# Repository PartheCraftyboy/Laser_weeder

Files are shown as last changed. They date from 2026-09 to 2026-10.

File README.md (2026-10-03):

# Jim — Precision 2-DOF Laser Weeding Gantry

<div align="center">








**Sub-millimeter autonomous laser weeding gantry system built on ROS 2 Jazzy, Gazebo Harmonic, and `ros2_control`.**

</div>

---

<div align="center">
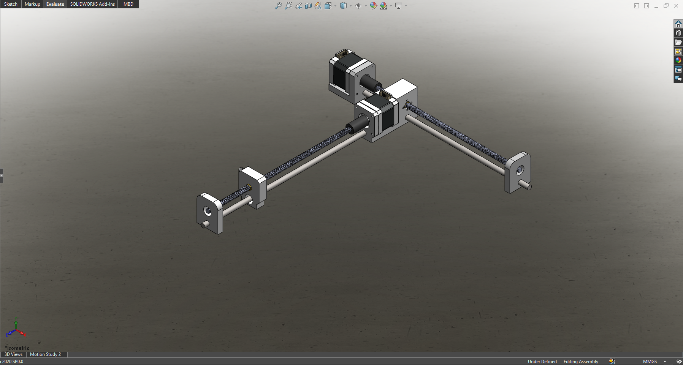
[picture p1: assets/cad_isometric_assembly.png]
Jim 2-DOF Gantry CAD Isometric Assembly
  
  <p><em>Figure 1: Full 3D CAD mechanical assembly of the Jim 2-DOF Cartesian laser weeding gantry.</em></p>
</div>

---

## 📖 Table of Contents

- [Executive Summary](#-executive-summary)
- [Mechanical & CAD Architecture](#-mechanical--cad-architecture)
  - [3D CAD Models & Assemblies](#3d-cad-models--assemblies)
  - [Finite Element Analysis (FEA)](#finite-element-analysis-fea)
  - [Kinematics & Hard Engineering Specs](#kinematics--hard-engineering-specs)
- [Software & Control Architecture](#-software--control-architecture)
  - [High-Level Dataflow](#high-level-dataflow)
  - [Coordinate Frames & TF Tree](#coordinate-frames--tf-tree)
  - [Defensible Engineering Decisions](#defensible-engineering-decisions)
- [ROS 2 Packages Breakdown](#-ros-2-packages-breakdown)
- [Quickstart Guide](#-quickstart-guide)
  - [Prerequisites](#prerequisites)
  - [One-Command Launch (Docker)](#one-command-launch-docker)
  - [Manual Docker Workflow](#manual-docker-workflow)
- [Targeting & Perception Pipeline](#-targeting--perception-pipeline)
  - [Field Generation](#field-generation)
  - [Oracle Weed Detector](#oracle-weed-detector)
  - [Analytical TF Targeting](#analytical-tf-targeting)
- [Hardware Implementation Roadmap](#-hardware-implementation-roadmap)
- [License & Acknowledgments](#-license--acknowledgments)

---

## 🌿 Executive Summary

**Jim** is an autonomous agricultural robot designed for targeted non-chemical weed eradication. Unlike bulky field robots or complex multi-axis articulated arms, Jim utilizes a static **2-DOF Cartesian gantry** suspended 300 mm above a 250 mm × 250 mm agricultural plot.

A downward-facing perception stack identifies weeds in real time, and the dual-axis gantry positions a focused optical laser beam with sub-millimeter precision over each weed meristem to eliminate it without disturbing adjacent crop root systems or compacting soil.

### Core Highlights
* **Zero Overhead IK**: Pure linear TF-based closed-form targeting in 4 lines of Python — no heavy OMPL or sampling configuration space required.
* **Deterministic Motion Control**: Driven via standard `ros2_control` and `JointTrajectoryController`.
* **Photorealistic Harmonic Simulation**: Complete field simulation in Gazebo Harmonic with dynamic procedural crop and weed distribution.
* **Oracle Perception with Synthetic Noise**: Fully decoupled perception testing with configurable runtime noise, miss rates, and false positives.
* **Containerized Environment**: Complete ROS 2 Jazzy + Gazebo Harmonic + GUI pass-through in Docker.

---

## ⚙️ Mechanical & CAD Architecture

The physical gantry is designed from the ground up for rigid, repeatable linear motion, thermal reliability, and rapid additive manufacturing.

<div align="center">
  <table>
    <tr>
      <td align="center" width="50%">
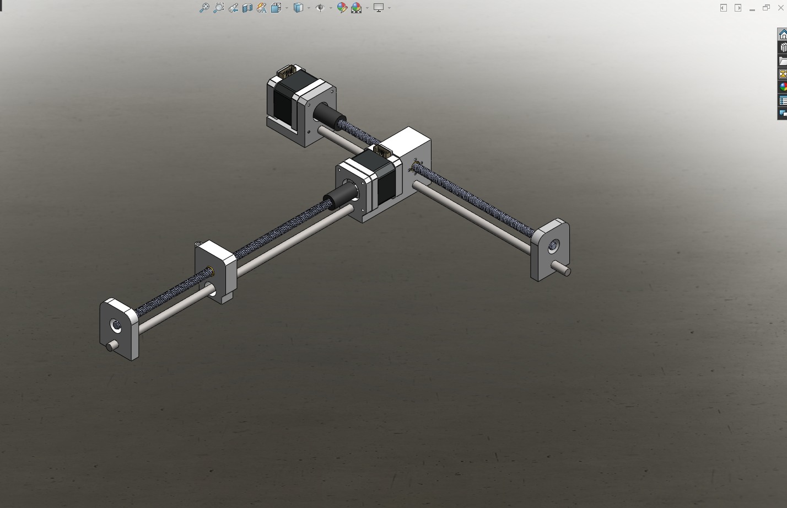
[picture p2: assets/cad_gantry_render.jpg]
CAD Gantry Render
        
        <br />
        <b>Dual-Axis Cross Gantry Assembly</b>
      </td>
      <td align="center" width="50%">
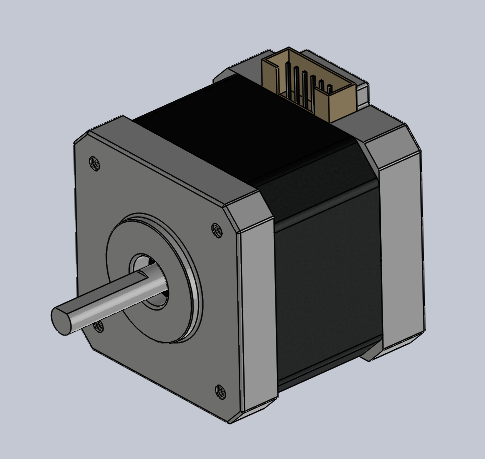
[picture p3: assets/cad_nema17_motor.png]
NEMA 17 Stepper Model
        
        <br />
        <b>NEMA 17 Stepper Actuator Model</b>
      </td>
    </tr>
  </table>
</div>

### 3D CAD Models & Assemblies

All CAD source files are housed under [`Main_Model/`](Main_Model/):
* **Master Assemblies**: `Main.SLDASM`, `jim_description.SLDASM` (configured for URDF/STL export).
* **2D Technical Drawings**: `D1_Main.SLDDRW` with detailed machining tolerances and hole patterns.
* **Drive Components**: T8 lead screws (`lead_screw.SLDPRT`), brass anti-backlash trapezoidal nuts (`nut.SLDPRT`), 8 mm hardened linear guide rods (`Rod.SLDPRT`), and flexible jaw couplers (`Coupler.SLDPRT`).
* **Custom Structural Brackets**: 3D printable brackets (`mount_bracket.STL`, `holding_bracket.STL`, `holding_bracket_y.STL`, `Part6.STL`, `Lazer block^X-axis.STL`).
* **Interchange Formats**: Standard `STEP` format (`Nima 17 40x42x5mm.STEP`) and motion study animation (`assets/cad_motion_study_xaxis.mp4`).

### Finite Element Analysis (FEA)

Structural rigidity is critical: any deflection in the motor bracket under rapid acceleration would translate into beam aiming error at the soil plane.

<div align="center">
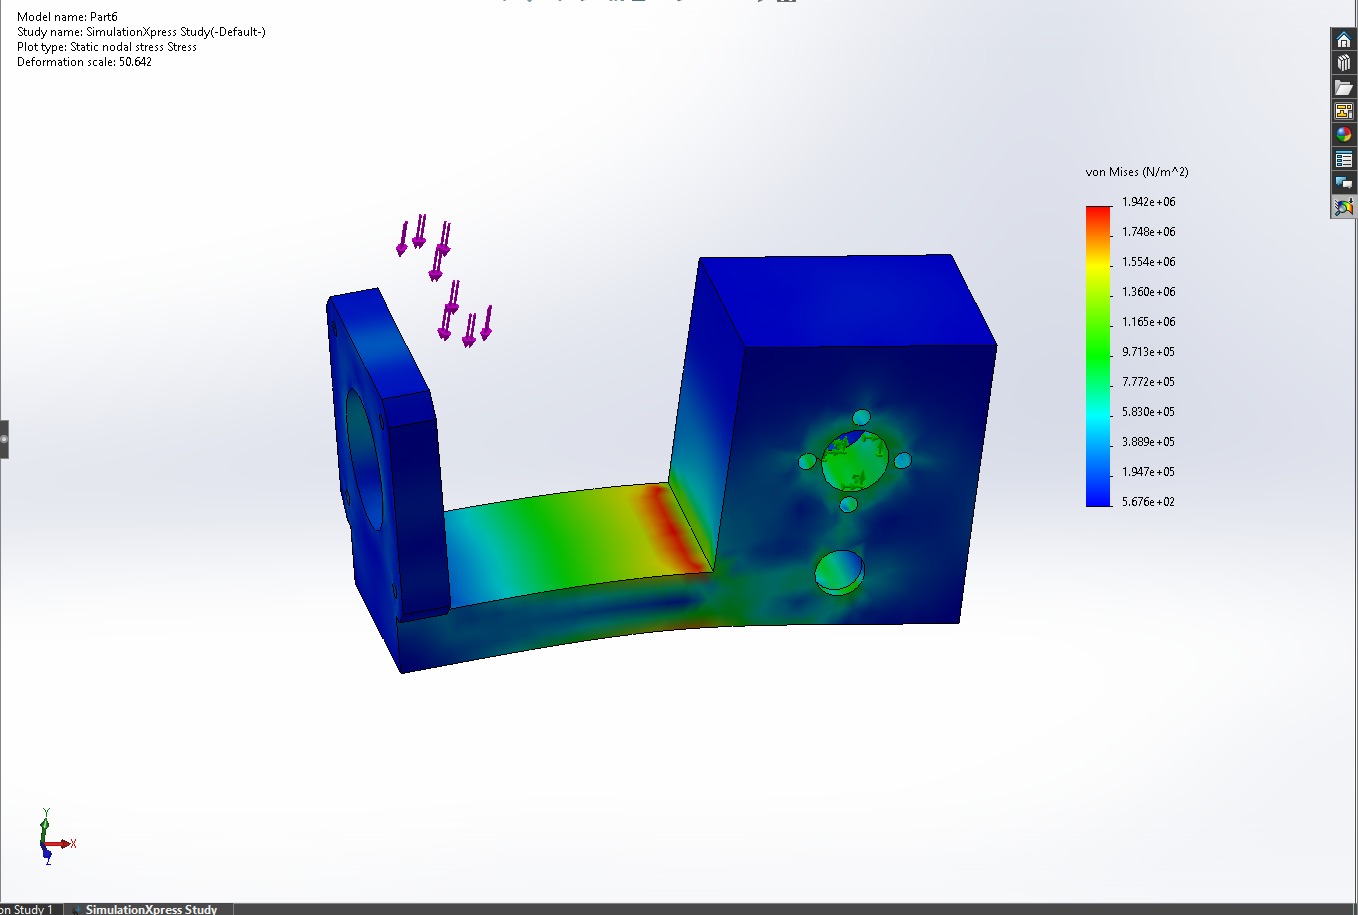
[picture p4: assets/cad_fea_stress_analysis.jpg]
SolidWorks SimulationXpress FEA
  
  <p><em>Figure 2: Finite Element Analysis (FEA) of motor mounting bracket (Part6) in SolidWorks SimulationXpress.</em></p>
</div>

* **Study**: Static nodal stress simulation (von Mises criterion).
* **Max von Mises Stress**: \(1.942 \times 10^6\text{ N/m}^2\) (\(\approx 1.94\text{ MPa}\)).
* **Structural Safety Margin**: Compared against the yield strength of structural PETG/PLA (\(> 45\text{ MPa}\)), the safety factor exceeds **20×**, ensuring zero structural deflection during gantry maneuvers.

### Kinematics & Hard Engineering Specs

| Parameter | Specification | Rationale & Engineering Formula |
| :--- | :--- | :--- |
| **Working Envelope** | \(250\text{ mm} \times 250\text{ mm}\) | Covers standard vegetable/nursery plot grid |
| **Z Height (Beam Clearance)** | \(300\text{ mm}\) above soil | Keeps optics clear of crop canopy and debris |
| **Lead Screws** | T8 (2 mm pitch, 4 starts) | **8 mm lead / revolution** for optimal speed-to-torque balance |
| **Guide Rails** | 8 mm precision hardened steel | Smooth rod with linear sleeve bearings |
| **Full Step Resolution** | **0.04 mm / full step** | \(8\text{ mm / rev} \div 200\text{ steps / rev} = 0.04\text{ mm}\) |
| **16× Microstepping Resolution** | **0.0025 mm / microstep** | \(8\text{ mm / rev} \div 3200\text{ steps / rev} = 2.5\ \mu\text{m}\) |
| **Maximum Safe Velocity** | **0.035 m/s** (\(35\text{ mm/s}\)) | **Lead screw critical whirling speed limit**: \(4.76 \times 10^6 \times 6.2 / 300^2 \approx 328\text{ RPM}\) (80% derated) |
| **Actuators** | NEMA 17 Stepper (1.8° step angle) | Standard form factor with high holding torque |
| **Operating Current** | **0.8 A – 1.0 A** *(NOT 1.5 A)* | 1.5 A drives casing to \(\sim 88^\circ\text{C}\); PLA glass transition \(T_g = 60^\circ\text{C}\) |
| **Torque Margin** | \(\approx 13\text{ mN}\cdot\text{m}\) vs \(400\text{ mN}\cdot\text{m}\) | **\(> 12\times\) holding margin**, preventing skipped steps |
| **Stepper Drivers** | MKS TMC2209 | SilentStepStick with StallGuard sensorless homing |

---

## 🧠 Software & Control Architecture

### High-Level Dataflow

```mermaid
flowchart TD
    subgraph Simulation ["Gazebo Harmonic & Physics"]
        GZ_WORLD["Ground Truth Field (Crops + Weeds)"]
        GZ_ROBOT["Jim URDF + gz_ros2_control Plugin"]
        GZ_CLOCK["Gazebo Clock"]
    end

    subgraph Bridges ["ROS-Gazebo Bridge"]
        BRIDGE_CLOCK["/clock Bridge"]
        BRIDGE_IMAGE["Camera / Image Bridge"]
    end

    subgraph Perception ["Perception & Detection"]
        ORACLE["oracle_detector<br/>(Reads ground_truth.yaml + injects noise)"]
    end

    subgraph Control ["Targeting & Control Stack"]
        TF["TF2 Listener<br/>(/tf & /tf_static)"]
        TARGETING["targeting_node<br/>(Analytical IK: closed-form linear delta)"]
        JTC["JointTrajectoryController<br/>(/gantry_controller)"]
        JSB["joint_state_broadcaster<br/>(/joint_states)"]
    end

    subgraph Visualization ["Operator Interface"]
        RVIZ["RViz2 Visualization<br/>(Aim ray, targets, weed markers)"]
    end

    GZ_CLOCK --> BRIDGE_CLOCK
    GZ_WORLD -.->|Known coordinates| ORACLE
    ORACLE -->|/weeds/detections| TARGETING
    ORACLE -->|/weeds/markers| RVIZ
    
    JSB -->|/joint_states| TARGETING
    JSB -->|/joint_states| TF
    TF --> TARGETING
    
    TARGETING -->|/gantry_controller/joint_trajectory| JTC
    TARGETING -->|/targeting/markers| RVIZ
    JTC --> GZ_ROBOT
```

### Coordinate Frames & TF Tree

The system is strictly [REP-103](https://www.ros.org/reps/rep-0103.html) compliant (metres, radians, SI units). Exactly **one** unit conversion exists in the entire stack (inside the hardware interface).

```
world
└── base_link                    (300 mm above soil plane)
    ├── x_carriage               (prismatic joint_x, 180° roll from CAD export)
    │   └── y_carriage           (prismatic joint_y)
    │       └── laser_aim_link   (Z-axis IS the optical beam direction)
    └── work_surface             (Soil plane, origin at center of reachable plot)
                                 Static TF: (0.1837, -0.2516, -0.3000) from base_link
```

> [!NOTE]
> **CAD 180° Roll Convention**: `joint_x` carries a 180° roll offset from the CAD export, causing machine \(+Y\) to translate along world \(-Y\). Consequently, `targeting_node.solve()` negates `joint_y`. This is a deliberate, defensible kinematic convention, not a bug.

### Defensible Engineering Decisions

1. **NO Nav2**: Jim is a static Cartesian gantry. There is no mobile differential base, no wheel odometry, and no navigation costmap. Omitting Nav2 eliminates unnecessary computational overhead.
2. **NO MoveIt**: For a 2-DOF Cartesian gantry, inverse kinematics is simply the identity function plus constant transform offsets. Moving `joint_x` by \(\Delta x\) moves the laser beam by \(\Delta x\) on the world frame. `targeting_node.py` solves this in 4 lines via `tf2` without needing OMPL configuration space sampling.
3. **Synthetic Oracle Perception**: Rather than coupling gantry testing to the stochastic quality of a neural network detector, the `oracle_detector` reads exact ground-truth field data and injects configurable Gaussian noise, false positives, and missed detections. This allows unit testing and edge-case benchmarking at will.
4. **Collision Geometry in Simulation**: Carriages on this machine do not self-intersect in real life. Redundant internal collision boxes in the URDF are stripped to prevent Gazebo contact engine pinning.

---

## 📦 ROS 2 Packages Breakdown

```
Jim/
├── ws/src/
│   ├── jim_description/         # Mechanical definition & kinematics
│   │   ├── meshes/              # Exported STL meshes (base_link, x_carriage, y_carriage)
│   │   ├── urdf/
│   │   │   ├── jim.urdf.xacro   # Complete robot URDF model with kinematics
│   │   │   └── jim.ros2_control.xacro # Hardware interface tags for gz_ros2_control
│   │   └── launch/display.launch.py   # Quick visual inspection in RViz
│   │
│   ├── jim_bringup/             # Controller configurations & base simulation
│   │   ├── config/controllers.yaml    # JointTrajectoryController & JSB settings
│   │   ├── launch/sim.launch.py       # Spawns gantry in empty Gazebo world
│   │   └── worlds/jim_world.sdf       # Minimalist Gazebo world
│   │
│   └── jim_sim/                 # Complete capstone simulation & targeting
│       ├── config/ground_truth.yaml   # Auto-generated plant & weed coordinates
│       ├── config/field.rviz          # RViz layout with camera & markers
│       ├── jim_sim/
│       │   ├── oracle_detector.py     # Perception node with noise injection
│       │   └── targeting_node.py      # TF analytical inverse kinematics solver
│       ├── launch/field.launch.py     # Orchestrated one-click capstone launch
│       ├── scripts/generate_field.py  # Procedural agricultural field generator
│       └── worlds/jim_field.sdf       # Photorealistic generated agricultural world
│
├── Main_Model/                  # SolidWorks CAD files, FEA, drawings, and STLs
├── assets/                      # High-res images, diagrams, and video assets for docs
├── compose.yaml                 # Docker Compose configuration with GUI pass-through
├── Dockerfile                   # Ubuntu 24.04 + ROS 2 Jazzy desktop full
└── run.sh                       # Automated cleanup, build, and launch script
```

---

## 🚀 Quickstart Guide

### Prerequisites
* **Linux Host** (Ubuntu 22.04 or 24.04 recommended)
* **Docker Engine** & **Docker Compose**
* **X11 display server** (for Gazebo & RViz GUI pass-through)

```bash
# 1. Clone the repository
# Via SSH:
git clone git@github.com:PartheCraftyboy/Laser_weeder.git

# Or via HTTPS:
# git clone https://github.com/PartheCraftyboy/Laser_weeder.git

cd Laser_weeder
```

### One-Command Launch (Docker)

The repository includes a self-healing launch script [`run.sh`](run.sh) that configures user permissions, spawns Docker, purges stale daemon nodes, compiles the workspace with symlink install, and triggers the full capstone simulation:

```bash
chmod +x run.sh
./run.sh
```

### Manual Docker Workflow

If you prefer step-by-step manual execution:

```bash
# 1. Authorize local container to connect to X11 display
xhost +local:docker

# 2. Build and start the container
export HOST_UID=$(id -u) HOST_GID=$(id -g)
docker compose up -d

# 3. Enter container shell
docker exec -it jim bash

# 4. Inside container: build ROS 2 workspace
cd ~/ws
colcon build --symlink-install
source install/setup.bash

# 5. Launch full capstone field demo
ros2 launch jim_sim field.launch.py
```

---

## 🎯 Targeting & Perception Pipeline

### Field Generation
The procedural generator [`generate_field.py`](ws/src/jim_sim/scripts/generate_field.py) creates realistic crop rows, weeds within the gantry reach, out-of-reach weeds, perimeter walls, and treelines, exporting both `jim_field.sdf` and `ground_truth.yaml`:

```bash
# Generate a fresh field with seed 42
cd ~/ws
python3 src/jim_sim/scripts/generate_field.py --seed 42
```

### Oracle Weed Detector
The `oracle_detector` node simulates a perception camera system. You can dynamically stress-test the targeting logic using ROS 2 parameters:

```bash
# Inject Gaussian position noise (standard deviation in meters)
ros2 param set /oracle_detector position_noise_std 0.005

# Inject a 30% random miss rate
ros2 param set /oracle_detector miss_rate 0.3

# Inject a 20% false positive rate
ros2 param set /oracle_detector false_positive_rate 0.2
```

### Analytical TF Targeting
The `targeting_node` subscribes to `/weeds/detections`, computes the nearest un-treated weed in the `work_surface` frame, verifies workspace bounds with safety margins (\(250\text{ mm} - 2\text{ mm}\)), and commands smooth trajectories to `/gantry_controller/joint_trajectory`.

To manually step through targets one by one:
```bash
# Set auto_cycle parameter to false
ros2 param set /targeting_node auto_cycle false

# Trigger targeting for next weed
ros2 service call /targeting_node/treat_next std_srvs/srv/Trigger
```

---

## 🛠️ Hardware Implementation Roadmap

```
[ ROS 2 Stack ] 
       │ (Target Trajectory / Setpoints)
       ▼
[ serial_hardware_interface (C++) ]
       │ (USB Serial: G-code or Binary Packets)
       ▼
[ Microcontroller (Arduino / Teensy 4.0) ]
       │ (STEP / DIR / ENABLE / UART)
       ▼
[ MKS TMC2209 SilentStepStick Drivers ]
 ├── StallGuard4 (Sensorless homing via back-EMF detection)
 └── StealthChop2 (Silent voltage-mode positioning)
       │
[ NEMA 17 Stepper Motors -> T8 Lead Screws -> Gantry Head ]
```

1. **Hardware Interface Plugin**: Implement a `hardware_interface::SystemInterface` communicating over USB serial with the motor controller.
2. **Sensorless Homing**: Leverage TMC2209 StallGuard4 to calibrate \(X_0, Y_0\) origin without mechanical limit switches.
3. **Laser Interlock**: Implement a hardware-level safety relay connected to an enclosure interlock and E-stop.

---

## 📜 License & Acknowledgments

This project is licensed under the **MIT License** — see the [LICENSE](LICENSE) file for details.

Developed as a Robotics Capstone Project. Special thanks to the open-source ROS 2, Gazebo, and SolidWorks communities.

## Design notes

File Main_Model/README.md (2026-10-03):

# Jim — Mechanical CAD & Hardware Models

This directory contains the complete mechanical design, 3D CAD models, finite element analysis (FEA), and technical drawings for the **Jim 2-DOF Cartesian Laser Weeding Gantry**.

---

## 📐 Overview

The machine is a precision two-axis Cartesian gantry designed to operate over a **250 mm × 250 mm** agricultural target plot. The gantry moves an optical laser targeting head across the soil surface with high positioning accuracy (\(\pm 0.04\text{ mm}\) full-step resolution).

```
                      +-----------------------------+
                      |   NEMA 17 Stepper (X-Axis)  |
                      +--------------+--------------+
                                     | (Flexible Coupler)
                                     v
                       [T8 Lead Screw + 8mm Guide]
                                     |
                      +--------------v--------------+
                      |       X-Carriage Block      |
                      +--------------+--------------+
                                     | (NEMA 17 Y-Axis)
                                     v
                       [T8 Lead Screw + 8mm Guide]
                                     |
                      +--------------v--------------+
                      |   Y-Carriage / Laser Head   |
                      +-----------------------------+
```

---

## 📁 File Manifest

| File | Type | Description |
| :--- | :--- | :--- |
| `Main.SLDASM` | SolidWorks Assembly | Master CAD assembly of the complete 2-axis gantry |
| `jim_description.SLDASM` | SolidWorks Assembly | Assembly configured for URDF mesh export to ROS 2 |
| `D1_Main.SLDDRW` | SolidWorks Drawing | 2D technical engineering drawing and tolerances |
| `Nima 17 40x42x5mm.STEP` | STEP Standard | Neutral CAD interchange model of the NEMA 17 stepper |
| `Nima 17 40x42x5mm.SLDPRT` | SolidWorks Part | Native SolidWorks NEMA 17 42mm stepper motor model |
| `lead_screw.SLDPRT` | SolidWorks Part | T8 Lead Screw (2 mm pitch, 4 starts = 8 mm lead) |
| `Rod.SLDPRT` | SolidWorks Part | 8 mm precision hardened steel linear guide rail |
| `nut.SLDPRT` | SolidWorks Part | T8 brass trapezoidal lead screw nut |
| `Coupler.SLDPRT` | SolidWorks Part | 5 mm to 8 mm flexible jaw shaft coupler |
| `Lazer block.SLDPRT` / `.STL` | SolidWorks / STL | Laser diode module mount & aim collimator |
| `holding_bracket.SLDPRT` / `.STL` | SolidWorks / STL | End support bracket for guide rod and lead screw |
| `holding_bracket_x.SLDPRT` | SolidWorks Part | X-axis rail end anchor bracket |
| `holding_bracket_y.SLDPRT` / `.STL`| SolidWorks / STL | Y-axis guide rail carriage bracket |
| `mount_bracket.SLDPRT` / `.STL` | SolidWorks / STL | NEMA 17 motor face mount bracket |
| `Part6.SLDPRT` / `Part6.STL` | SolidWorks / STL | Structural cross-carriage mounting block |
| `Part2.SLDPRT`, `Part3.SLDPRT` | SolidWorks Parts | Auxiliary structural framing members |
| `Isometric_ss_asm.png` | Image | High-resolution isometric render of the full assembly |
| `Pic1.PNG` | Image | Close-up render of NEMA 17 actuator model |
| `X-axis.mp4` | Video | SolidWorks motion study animation showing X-axis translation |
| `WhatsApp Image 2026-09-03...` | Image | FEA static nodal stress analysis of `Part6` |
| `WhatsApp Image 2026-09-06...` | Image | Alternative perspective render of gantry assembly |

---

## 🔬 Finite Element Analysis (FEA)

Static stress analysis was conducted in **SolidWorks SimulationXpress** on the critical structural load-bearing member (`Part6` motor holding bracket) to evaluate rigidity and prevent deflection under drive torque and dynamic carriage acceleration:

* **Study Type**: Static nodal stress study (von Mises)
* **Maximum von Mises Stress**: \(1.942 \times 10^6\text{ N/m}^2\) (\(\approx 1.94\text{ MPa}\))
* **Material**: Structural Thermoplastic (PLA / PETG)
* **Yield Strength**: \(> 45\text{ MPa}\) (PETG / PLA)
* **Safety Factor**: \(> 20\times\), confirming that deflection is negligible under operational loads.

---

## 🖨️ 3D Printing Recommendations

For fabrication of custom structural brackets (`*.STL`):

* **Material**: PETG or ABS recommended (PLA acceptable if stepper motors are thermally derated to \(\le 1.0\text{ A}\)).
* **Layer Height**: 0.20 mm (0.16 mm for nut mounting surfaces).
* **Perimeters / Walls**: 4 to 5 perimeters for mechanical stiffness.
* **Infill**: 40%–50% Gyroid or Grid infill.
* **Dimensional Accuracy**: Ensure calibrated horizontal expansion for bearing press-fits and 8 mm smooth rod bores.

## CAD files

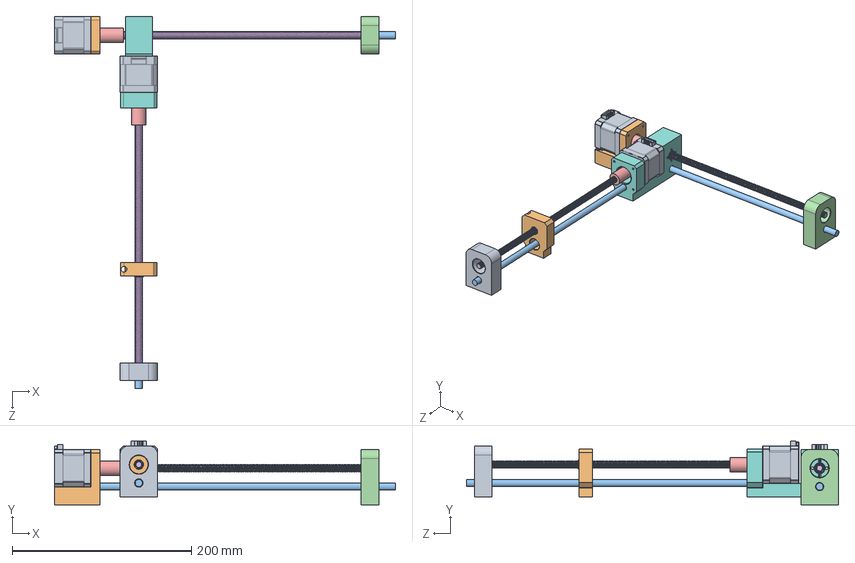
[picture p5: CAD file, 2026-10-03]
Main_Model/Main.SLDASM
380.8 x 71.3 x 414.8 mm
Nima 17 40x42x5mm x 2
mount_bracket
Rod x 2
holding_bracket_x
Coupler x 2
lead_screw x 2
nut x 2
holding_bracket_y
Lazer block

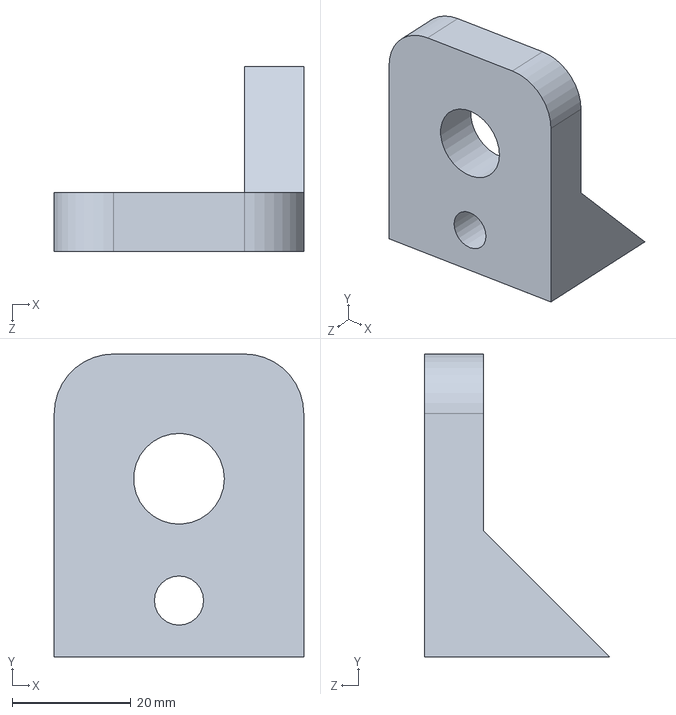
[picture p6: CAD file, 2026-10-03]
Main_Model/holding_bracket_x.SLDPRT
42.0 x 51.0 x 31.2 mm

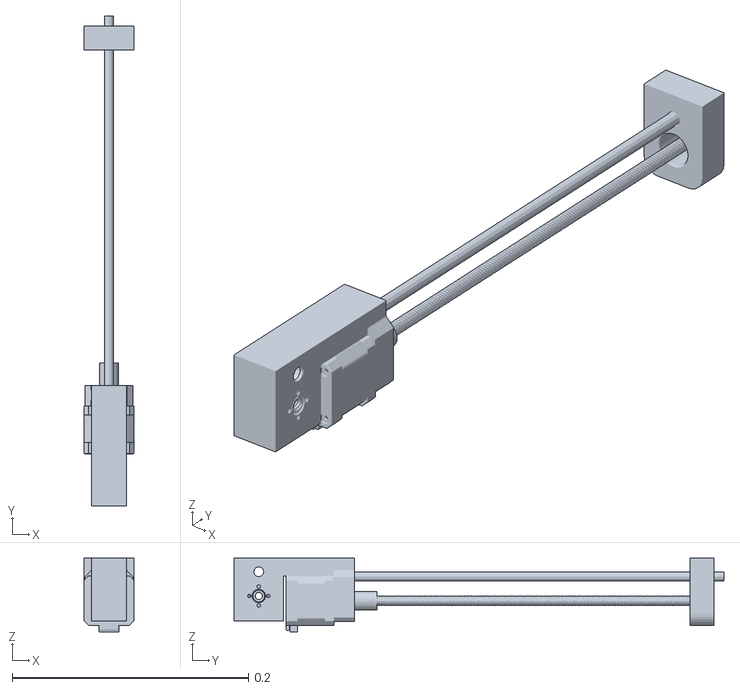
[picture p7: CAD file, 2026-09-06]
ws/src/jim_description/meshes/x_carriage.stl
0.042 x 0.415 x 0.0623

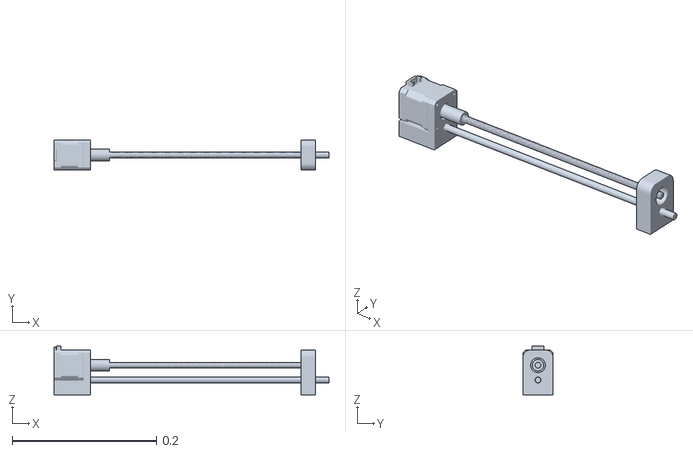
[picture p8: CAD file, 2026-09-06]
ws/src/jim_description/meshes/base_link.stl
0.381 x 0.042 x 0.0673

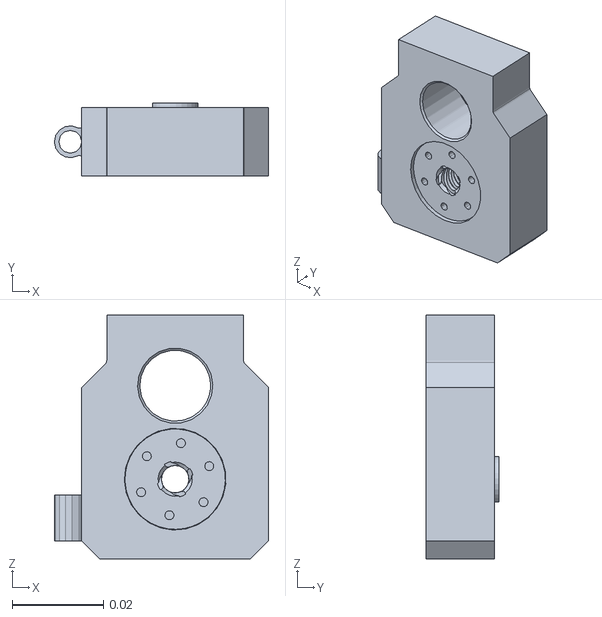
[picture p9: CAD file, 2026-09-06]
ws/src/jim_description/meshes/y_carriage.stl
0.047 x 0.016 x 0.0535

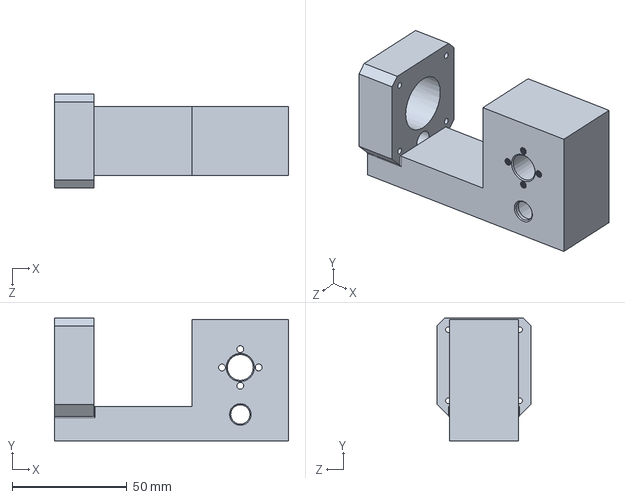
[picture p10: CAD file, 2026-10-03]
Main_Model/Part6.SLDPRT
102.0 x 53.5 x 41.0 mm

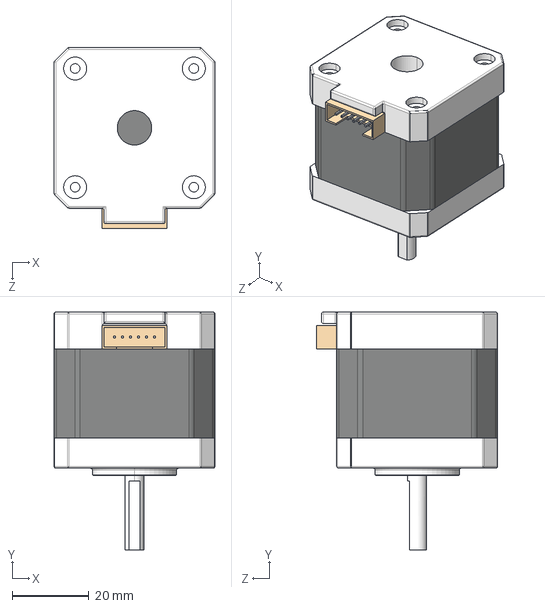
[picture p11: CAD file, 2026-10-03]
Main_Model/Nima 17 40x42x5mm.STEP
42.0 x 62.1 x 47.3 mm

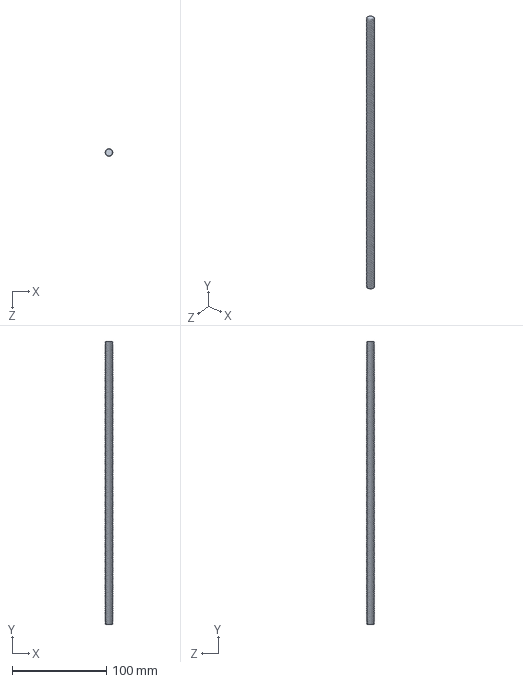
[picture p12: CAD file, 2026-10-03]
Main_Model/Part2.SLDPRT
8.00 x 300.0 x 8.00 mm

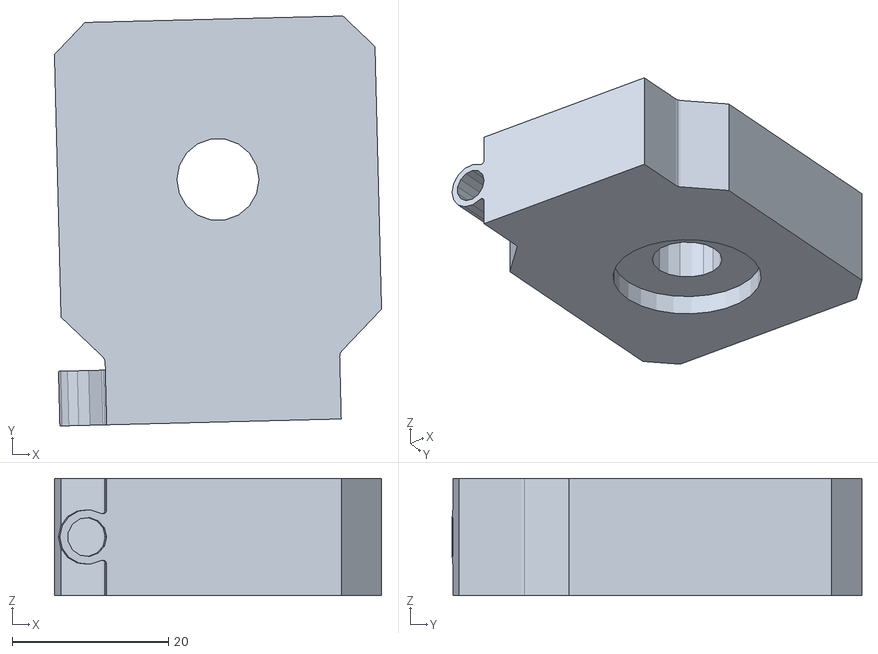
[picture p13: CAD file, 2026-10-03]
Main_Model/Lazer block^X-axis.STL
41.8 x 52.4 x 15.0

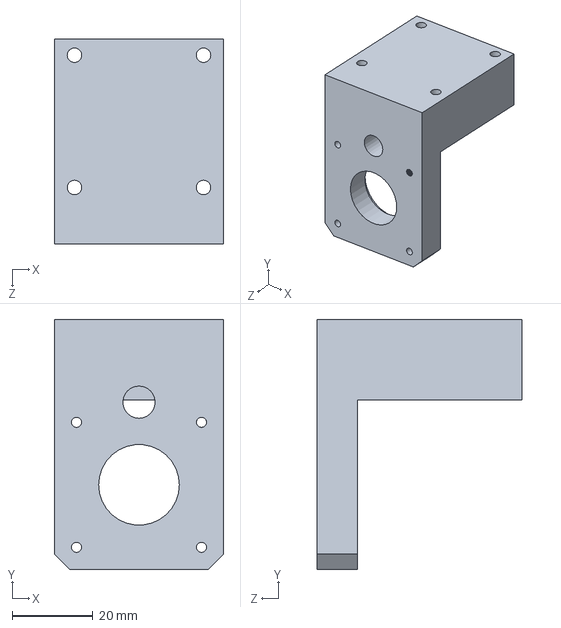
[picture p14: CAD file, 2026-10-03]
Main_Model/mount_bracket.SLDPRT
42.0 x 62.0 x 50.8 mm

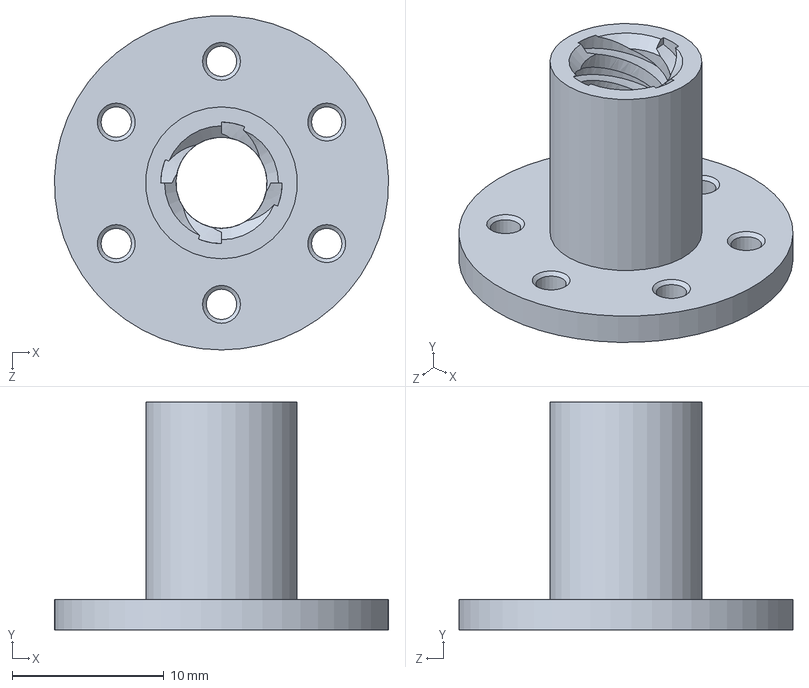
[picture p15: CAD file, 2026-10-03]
Main_Model/nut.SLDPRT
22.0 x 15.0 x 22.0 mm

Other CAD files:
Main_Model/jim_description.SLDASM
Main_Model/Coupler.SLDPRT
Main_Model/Lazer block.SLDPRT
Main_Model/Rod.SLDPRT
Main_Model/holding_bracket.SLDPRT
Main_Model/holding_bracket_y.SLDPRT
Main_Model/Part3.SLDPRT
Main_Model/D1_Main.SLDDRW
Main_Model/Nima 17 40x42x5mm.SLDPRT
Main_Model/Part6.STL
Main_Model/holding_bracket.STL
Main_Model/holding_bracket_y.STL
Main_Model/lead_screw.SLDPRT
Main_Model/mount_bracket.STL

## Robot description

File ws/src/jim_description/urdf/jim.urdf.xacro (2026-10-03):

<?xml version="1.0"?>
<!--
  Jim - laser weed removal gantry
  2-DOF Cartesian XY positioner

  Derived from the SolidWorks URDF export, with these corrections:
    * joint_y origin shifted back by one full travel (the Y nut was
      exported fully extended instead of homed)
    * collision geometry replaced with primitives (mesh collision on
      167k triangles would destroy the Gazebo solver)
    * masses and inertias overridden (no materials were assigned in CAD,
      so the exporter's values were ~4x too low)
    * package renamed, robot renamed, ROS 2 structure
-->
<robot xmlns:xacro="http://www.ros.org/wiki/xacro" name="jim">

  <!-- ==================================================================
       ARGUMENTS  (override at launch: xacro jim.urdf.xacro use_sim:=false)
       ================================================================== -->
  <xacro:arg name="use_sim" default="true"/>
  <xacro:arg name="params_file" default="$(find jim_bringup)/config/controllers.yaml"/>

  <!-- Height of base_link above the ground plane, metres. -->
  <xacro:property name="mount_height" value="0.30"/>

  <!-- ==================================================================
       PARAMETERS
       Everything tunable lives here. Change a number, rebuild, done.
       ================================================================== -->

  <!-- Mechanical travel, metres. Measured nut-face to end-support. -->
  <xacro:property name="travel_x" value="0.250"/>
  <xacro:property name="travel_y" value="0.250"/>

  <!-- Drivetrain. T8 lead screw, 2 mm pitch x 4 starts = 8 mm per rev.
       Not used by URDF directly - the hardware interface reads these to
       convert metres to steps. Kept here so there is one source of truth. -->
  <xacro:property name="screw_lead" value="0.008"/>
  <xacro:property name="steps_per_rev" value="200"/>
  <xacro:property name="microsteps" value="16"/>

  <!-- Velocity ceiling. Set by lead screw critical speed (whip), not by
       motor torque. 4.76e6 * 6.2 / 300^2 = 328 rpm, derated 80%, x 8 mm. -->
  <xacro:property name="max_vel" value="0.035"/>
  <xacro:property name="max_eff" value="50.0"/>

  <!-- Link masses, kg. Estimated - CAD had no materials assigned.
       Replace with weighed values before any dynamics work. -->
  <xacro:property name="mass_base" value="0.75"/>
  <xacro:property name="mass_xc" value="0.90"/>
  <xacro:property name="mass_yc" value="0.15"/>

  <!-- Joint origins straight from the CAD export. -->
  <xacro:property name="jx_xyz" value="0.073575 -0.018445 0.0064807"/>
  <xacro:property name="jx_rpy" value="3.14159265 0 0"/>

  <!-- Y origin CORRECTED: exporter gave 0.35117 (nut fully extended).
       Home is one full travel back from there. -->
  <xacro:property name="jy_y" value="${0.35117 - travel_y}"/>

  <xacro:property name="mesh" value="package://jim_description/meshes"/>

  <!-- ==================================================================
       MATERIALS
       ================================================================== -->
  <material name="jim_grey">  <color rgba="0.75 0.75 0.78 1.0"/></material>
  <material name="jim_gold">  <color rgba="0.95 0.76 0.18 1.0"/></material>
  <material name="jim_red">   <color rgba="0.85 0.15 0.15 1.0"/></material>

  <!-- ==================================================================
       INERTIA HELPER
       Solid cuboid about its own centre of mass. Good enough for
       position-controlled prismatic joints - the controller commands
       position, so inertia only shows up as second-order dynamics.
       ================================================================== -->
  <xacro:macro name="box_inertia" params="m x y z o_xyz">
    <inertial>
      <origin xyz="${o_xyz}" rpy="0 0 0"/>
      <mass value="${m}"/>
      <inertia ixx="${m*(y*y + z*z)/12.0}" ixy="0.0" ixz="0.0" iyy="${m*(x*x + z*z)/12.0}" iyz="0.0" izz="${m*(x*x + y*y)/12.0}"/>
    </inertial>
  </xacro:macro>

  <!-- ==================================================================
       LINKS
       ================================================================== -->

  <!-- base_link: frame, X motor, X coupler, X screw, X guide rods,
       both X end brackets. Anything bolted down or merely spinning. -->
  <link name="base_link">
    <xacro:box_inertia m="${mass_base}" x="0.381" y="0.042" z="0.067" o_xyz="0.1745 -0.0184 -0.0009"/>
    <visual>
      <origin xyz="0 0 0" rpy="0 0 0"/>
      <geometry><mesh filename="${mesh}/base_link.stl"/></geometry>
      <material name="jim_grey"/>
    </visual>
    <collision>
      <origin xyz="0.1745 -0.0184 -0.0009" rpy="0 0 0"/>
      <geometry><box size="0.381 0.042 0.067"/></geometry>
    </collision>
  </link>

  <!-- x_carriage: X nut, its block, AND the entire Y axis assembly -
       Y motor, Y coupler, Y screw, Y rods, Y end bracket. All of it
       rides on X, so all of it belongs to this link. -->
  <link name="x_carriage">
    <xacro:box_inertia m="${mass_xc}" x="0.042" y="0.415" z="0.062" o_xyz="-0.0119 0.1865 0.0009"/>
    <visual>
      <origin xyz="0 0 0" rpy="0 0 0"/>
      <geometry><mesh filename="${mesh}/x_carriage.stl"/></geometry>
      <material name="jim_gold"/>
    </visual>
  </link>

  <!-- y_carriage: Y nut, its block, laser head. -->
  <link name="y_carriage">
    <xacro:box_inertia m="${mass_yc}" x="0.047" y="0.016" z="0.054" o_xyz="-0.0154 0.007 0.0093"/>
    <visual>
      <origin xyz="0 0 0" rpy="0 0 0"/>
      <geometry><mesh filename="${mesh}/y_carriage.stl"/></geometry>
      <material name="jim_gold"/>
    </visual>
  </link>

  <!-- laser_aim_link: where the beam leaves the head, pointing down.
       This is the frame targeting actually solves for. Z is the beam
       direction, so a target is "put laser_aim_link over that point".
       Offset is a placeholder - measure it off the real head. -->
  <link name="laser_aim_link"/>

  <joint name="laser_aim_joint" type="fixed">
    <origin xyz="-0.0154 0.007 0.0175" rpy="0 0 0"/>
    <parent link="y_carriage"/>
    <child link="laser_aim_link"/>
  </joint>

  <!-- ==================================================================
       JOINTS
       ================================================================== -->

  <joint name="joint_x" type="prismatic">
    <origin xyz="${jx_xyz}" rpy="${jx_rpy}"/>
    <parent link="base_link"/>
    <child link="x_carriage"/>
    <axis xyz="1 0 0"/>
    <limit lower="0.0" upper="${travel_x}" effort="${max_eff}" velocity="${max_vel}"/>
  </joint>

  <joint name="joint_y" type="prismatic">
    <origin xyz="0.0005 ${jy_y} -0.004" rpy="0 0 0"/>
    <parent link="x_carriage"/>
    <child link="y_carriage"/>
    <axis xyz="0 1 0"/>
    <limit lower="0.0" upper="${travel_y}" effort="${max_eff}" velocity="${max_vel}"/>
  </joint>

  <!-- ==================================================================
       WORLD ANCHOR
       Gazebo treats a link literally named "world" as the static frame.
       Without this the gantry is a free body and falls through the floor.
       It also gives the kinematic tree an inertia-free root, which is
       what silences the KDL "root link has inertia" warning.
       ================================================================== -->
  <link name="world"/>

  <joint name="world_to_base" type="fixed">
    <origin xyz="0 0 ${mount_height}" rpy="0 0 0"/>
    <parent link="world"/>
    <child link="base_link"/>
  </joint>

  <!-- ==================================================================
       CONTROL
       ================================================================== -->
  <xacro:include filename="$(find jim_description)/urdf/jim.ros2_control.xacro"/>

  <xacro:jim_ros2_control use_sim="$(arg use_sim)" travel_x="${travel_x}" travel_y="${travel_y}" max_vel="${max_vel}" params_file="$(arg params_file)"/>

</robot>

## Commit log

2026-09-06 Jim: URDF from CAD + ros2_control + Gazebo Harmonic bringup
    - jim_description: xacro from SolidWorks export, corrected Y home offset
    (nut was exported fully extended), primitive collision, parameterised
    travel/lead/velocity, world anchor, laser_aim_link
    - jim_bringup: Gazebo world, controller config, sim launch with
    GZ_SIM_RESOURCE_PATH and /clock bridge
    - X axis moves correctly under JointTrajectoryController
    - KNOWN ISSUE: joint_y does not move. Setpoint ramps away from a
    stationary joint, so tolerance errors scale with whatever tolerance
    is set. Suspect self-collision between y_carriage and x_carriage.
    Next step: ros2 control list_hardware_interfaces, then try removing
    colli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
    [base_link.stl, controllers.yaml, jim.ros2_control.xacro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]
2026-09-07 Phase 3: field world, oracle detector, targeting node
    [jim_field.sdf]
2026-10-03 docs & cad: integrate 3D CAD models, FEA analysis, automated launch, and comprehensive presentation
    - Add master SolidWorks assemblies, parts, STLs, 2D drawings, and STEP files in Main_Model/
    - Add high-resolution CAD renders, motion study, and FEA stress analysis assets in assets/
    - Author comprehensive, visually rich root README.md with system architecture, hard engineering specs, and TF kinematics
    - Add Main_Model/README.md with BOM, fabrication guide, and FEA simulation parameters
    - Fix joint_y carriage self-collision geometry in jim.urdf.xacro
    - Fix jim_sim packaging with setup.cfg (install scripts to libexec) and glob pattern in setup.py
    - Update procedural field generator and SDF worl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
    [Coupler.SLDPRT, D1_Main.SLDDRW, Lazer block.SLDPRT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]
